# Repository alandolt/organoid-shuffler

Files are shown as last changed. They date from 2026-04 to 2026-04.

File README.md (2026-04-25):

# MicroNinjas - Organoid Sorting

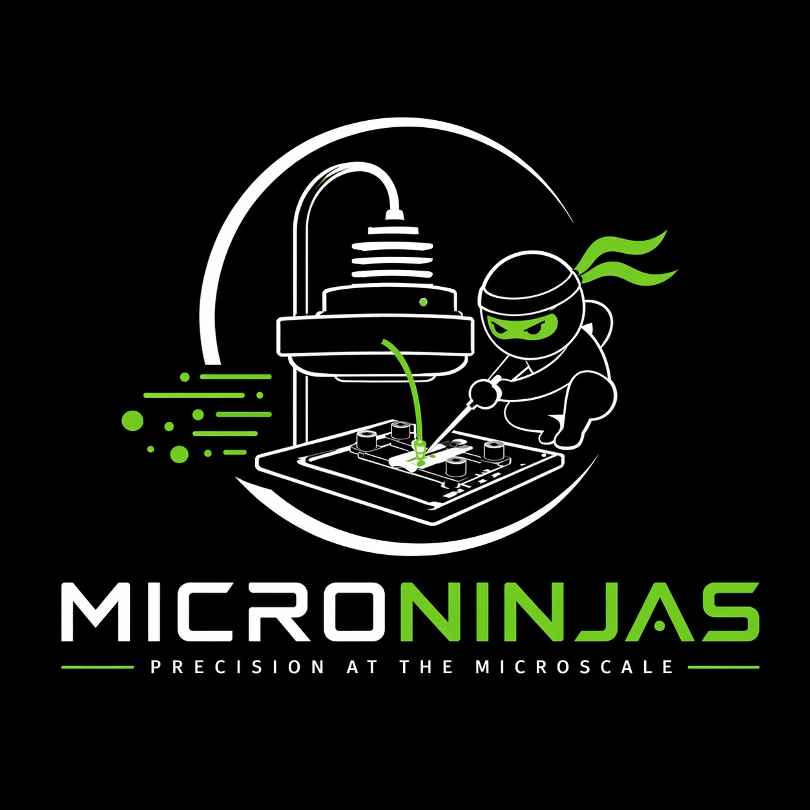
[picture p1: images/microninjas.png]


*EMBO Hackathon Hack your Microscope 2026 in Oeiras, Portugal.*

This project was developed during a hands-on hackathon focused on building open, functional microscopy and microfluidic systems from the ground up. The goal was not just to prototype ideas, but to design, build, and test complete working pipelines under real constraints.

Participants: Alex Landolt, Mai Rahmoon, Olyssa Sperling, Kartik Totlani, Enrico Piperno

Tutors: Sunil Kumar, Dumisile Lumkwana 

## The challenge
We tackled size-based sorting of organoids in microfluidic flow.

The task required:

* Detecting organoids in real time inside a microfluidic chip
* Classifying them based on size
* Actively sorting them into multiple outlets
* Closing the loop with automated control and verification

We built a closed-loop system that integrates: flow → image → classify → actuate → verify

## [Brainstorming and Fabrication of microfluidic chip](https://github.com/alandolt/organoid-shuffler/blob/master/Microfluids1x1.md)

## Experimental setup
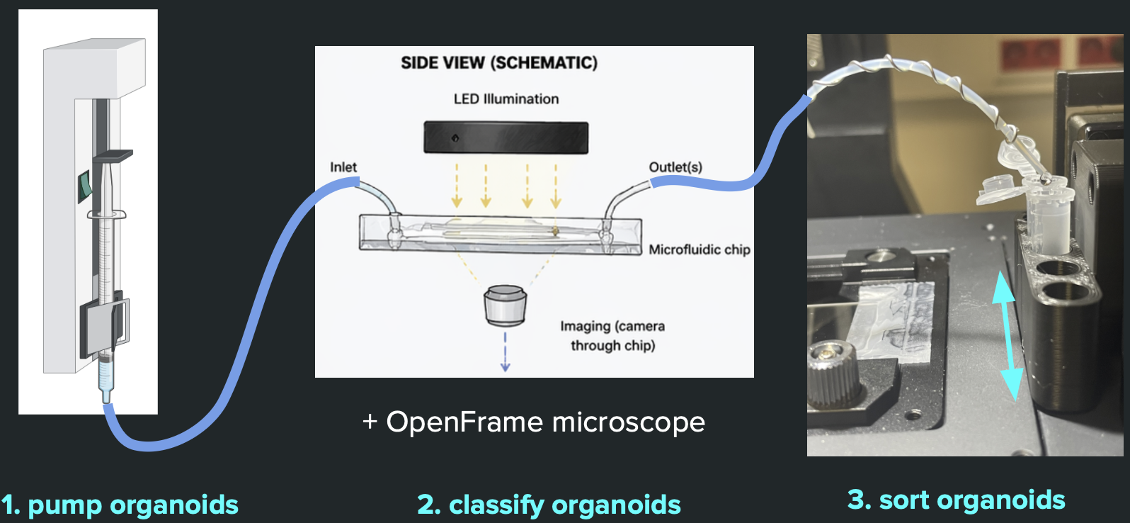
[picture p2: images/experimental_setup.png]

The final experimental setup consists of:

* one automatable syringe pump by the [Poseidon design](https://github.com/pachterlab/poseidon)
* a [microfluidic chip by IBIDI](https://ibidi.com/channel-slides/50--slide-i-luer.html) mounted on an [OpenFrame fluorescence microscope](https://cairn-research.co.uk/product/openframe-microscope/) by cairn research
* the sorting mechanism crafted by a one-axis translation stage, and a 3D printed 0.5 ml [Eppendorf tube adapter](eppendorf_0.5ml_adapter.stl).
The parts are connected using silicon and teflon tubing.

## Microfluidic actuation
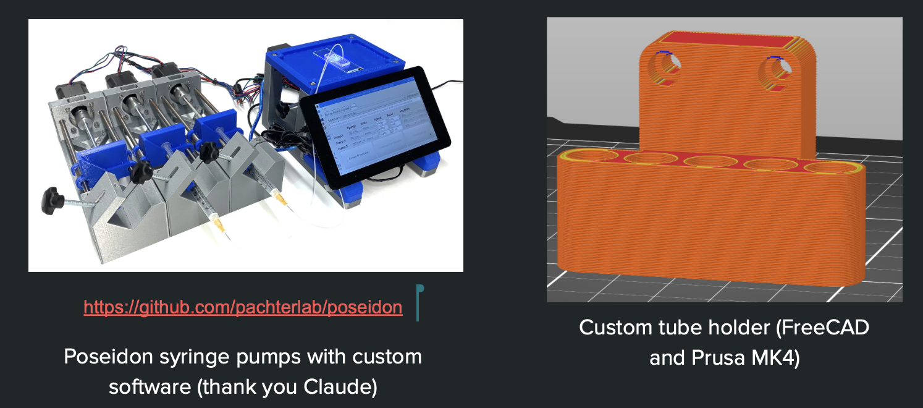
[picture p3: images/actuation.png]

We actuated our microfluidic chips with the open-source Poseidon design. 
We wrote custom scripts to actuate the stepper motors and then calibrated the pumps to convert from steps to mm (travel stage dependent) and then mm to ml (syringe dependent). 
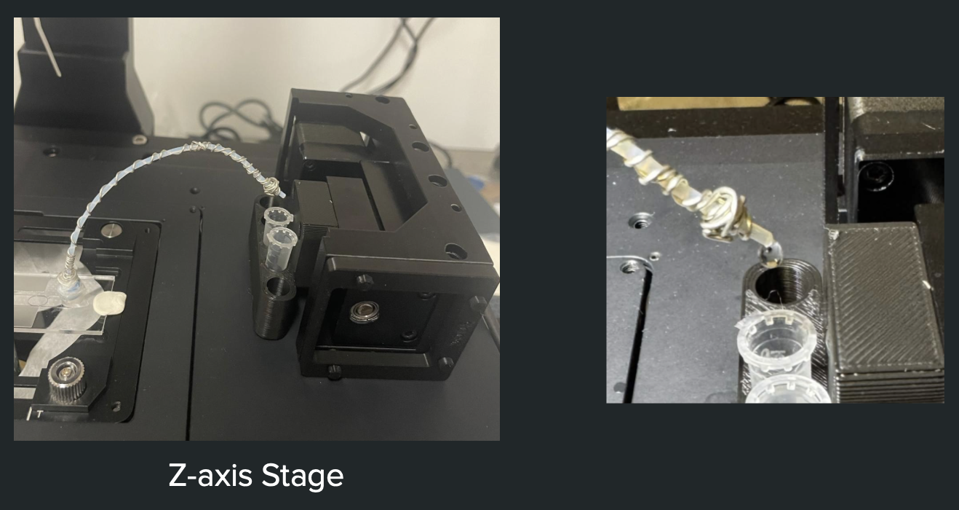
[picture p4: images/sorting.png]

This way we were able control flow precisely up to 1 ul/s. The pump control was done manually first with cnc_stepper_motor.py and cnc_stepper_motor.ino flashed on the Arduino UNO. 

## Image analysis
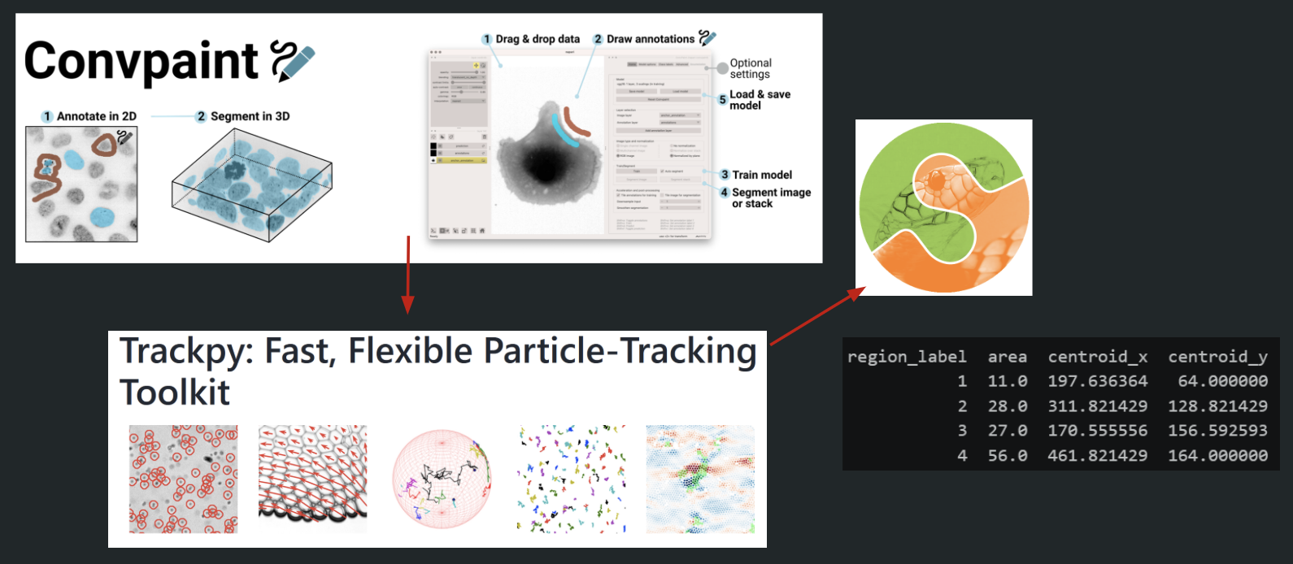
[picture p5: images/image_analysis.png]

Using the syringe pumps we achieved a controlled flow of organoids through the chip that was imaged in real-time at 1 f/s. 
In order to use the pipeline, please follow the instructions in the notebook Pipeline.ipynb, which will guide you through the different steps of the pipeline.
The pipeline does the following steps:
* Snaps an image from the microscope
* Segments the image using the trained Convpaint model
* Cleans up the segmentation mask using some morphological operations
* Measures the size of the detected organoids (the segmented objects in class 2)
* Tracks the detected organoids across frames using trackpy
* If an organoid is detected that is bigger than 100 pixels in the field of view, it moves it to eppendorf slot 1 for 30s, otherwise it moves it to slot 0.
* All detections and sorting decisions are logged in a parquet file for later analysis.
* The flow in the chip is controlled by setting a flowrate of 0.001 ml/min in the pump that controls the flow rate in the chip (the one connected to the inlet). You can directly set the flowrate through the jupyter notebook.

## Results
(https://youtu.be/Kiy7haI36f4 "Click to play on Youtube.com")

## Discussion
The organoids were smaller and rarer than expected since the sample was very dilute. 

In the end we managed to find some, train the classification model on them and start the sorting procedure.

In the future we can use the speed calculation in order to calculate the time of the organoid reaching the end of the tubing, matching the exact time for the organoid to drop into the sorting Eppendorf tubings.

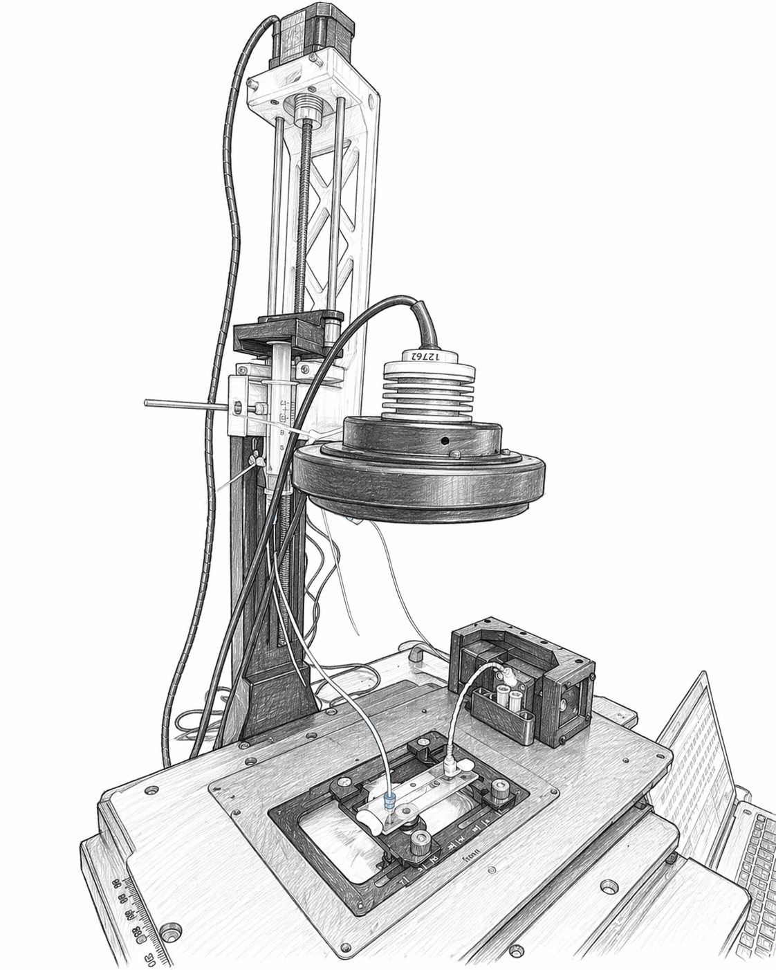
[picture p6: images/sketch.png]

Sketch generated using ChatGPT that very accurately represents our setup.

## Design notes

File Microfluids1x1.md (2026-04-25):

# Challenge -1: Organoid sorting

## Brainstorming on possible microfluidic device configuration

### 1. Passive spiral sorter without active sorting

A possible way to sort particles of different sizes passively is using a spiral microfluidic device with 2 inlets and several outlets. Over the course of flow, the particles can be separated based on inertia and centrifugal forces. Since the real time imaging and feedback-controlled sorting was a deliverable of the course, the spiral sorter chip wasn’t used.

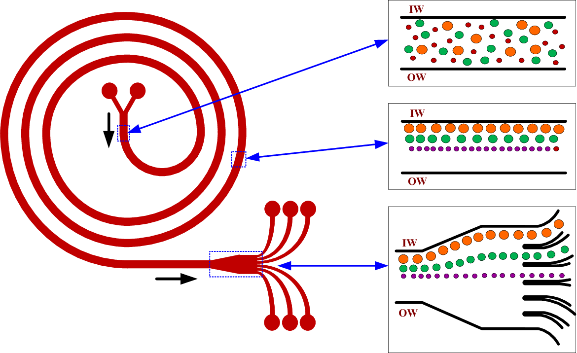
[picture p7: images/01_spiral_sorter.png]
Passive spiral sorter schematic


### 2. Microfluidic device with detection and hydrodynamic actuation

A possible solution to sort particles based on the size was using a microfluidic channel with hydrodynamic actuation using image driven flow control (as shown in the figure below). Briefly, the organoids can be injected and spaced using a sheath flow towards the imaging area, where the detection and analysis occur. Once the sorting decision is made, the flow is actuated within the channel to drive the organoids into one of the collection channels.

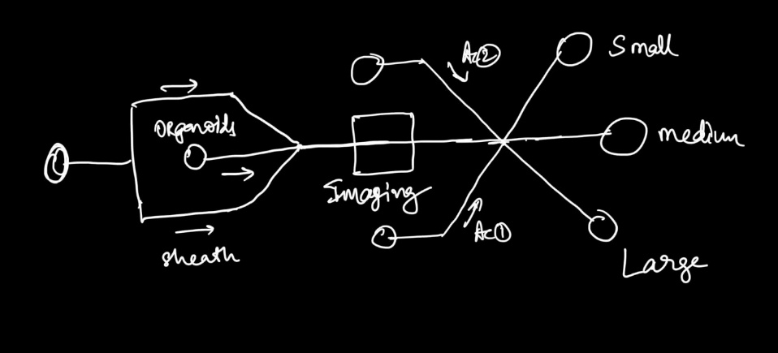
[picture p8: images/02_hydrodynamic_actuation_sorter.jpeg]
Hydrodynamic actuation-based sorting schematic


### 3. Simple microfluidic device for imaging and sorting controlled by linear collection control

The third option was to use a simple microfluidic device (single inlet and single outlet) for imaging the organoids on chip and automating the collection. The mold for the Eppendorf tubes was 3D printed and mounted on a X-Y linear motor. The imaging, analysis an

## Microfabrication

We used two methods to fabricate the microfluidic devices used for the project.

### 1. Laser cutting

PMMA sheets as well as dual sided tape were cut using a CO₂ laser (add a link to the laser cutter).

Laser-cut microfluidic devices were rapidly fabricated by structuring poly(methyl methacrylate) (PMMA) sheets and assembling them with double-sided adhesive tape as an intermediate spacer and bonding layer. In this approach, channel geometries and inlet/outlet ports were first defined in CAD and transferred to PMMA and adhesive films using a CO₂ laser cutter, with the adhesive layer typically determining the channel height (180 µm). After cutting, the layers were aligned using inlet holes and laminated together by pressing the adhesive between rigid PMMA substrates, forming enclosed microchannels without the need for cleanroom processing.

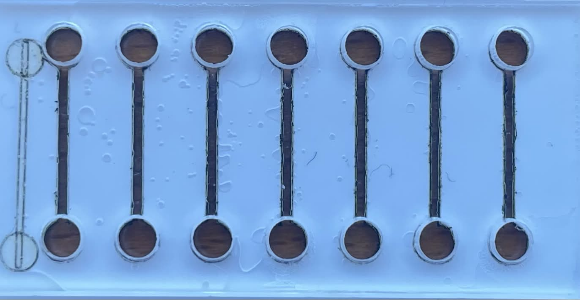
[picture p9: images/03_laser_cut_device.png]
Laser-cut microfluidic devices


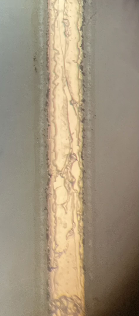
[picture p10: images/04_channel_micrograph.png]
Laser-cut channel micrograph


### 2. Soft lithography

Soft lithography is the standard method for fabricating microfluidic devices due to its high resolution and reliability. PDMS stamps were prepared by pouring a mixture of PDMS elastomer and curing agent (typically in a 10:1 weight ratio) over a microstructured silicon wafer mold. The mixture is degassed to remove air bubbles and then cured at elevated temperatures (typically 65-150 °C). After curing, the PDMS layer was peeled from the mold, diced into individual devices, and inlet / outlet ports are created using biopsy punches. The PDMS devices were subsequently cleaned and irreversibly bonded to glass substrates using oxygen plasma treatment, forming enclosed microfluidic channels.

[Soft lithography reference DOI](https://doi.org/10.1002/(SICI)1521-3773(19980316)37:5%3C550::AID-ANIE550%3E3.0.CO;2-G)

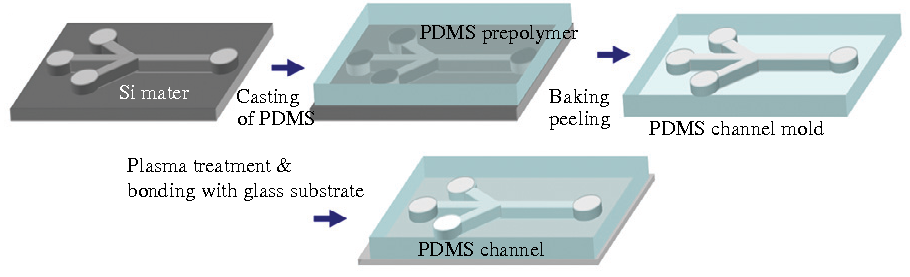
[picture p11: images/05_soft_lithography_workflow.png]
Soft lithography workflow


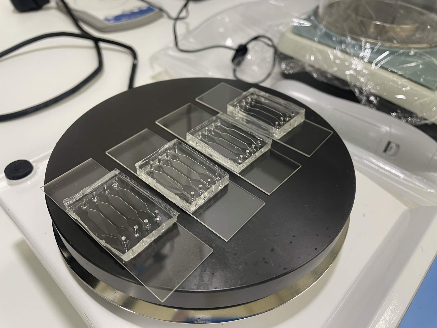
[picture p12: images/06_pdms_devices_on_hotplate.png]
PDMS devices on a hotplate


Microfluidic device schematic

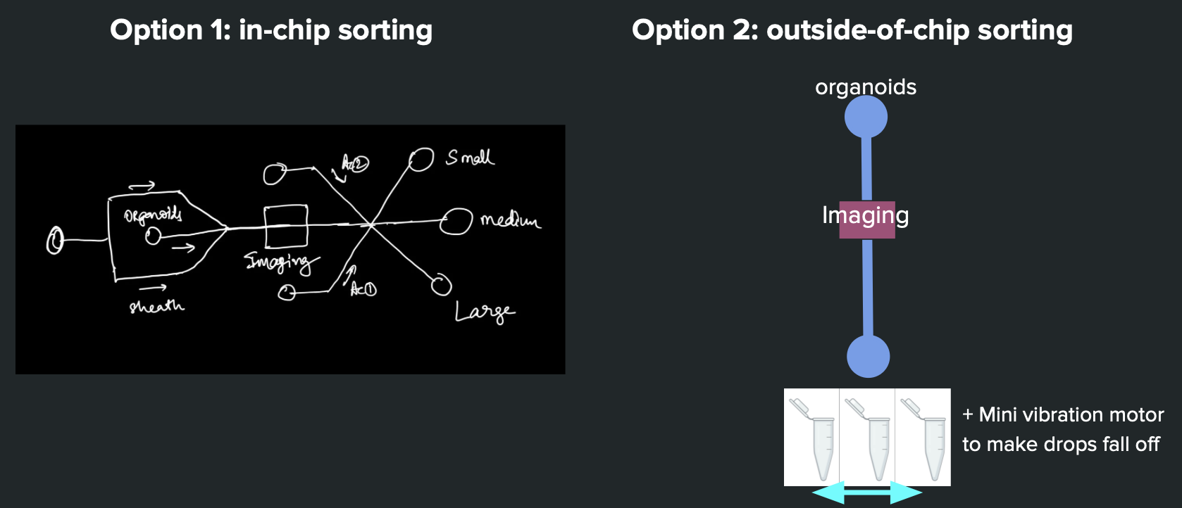
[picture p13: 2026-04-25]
images/chip_design.png

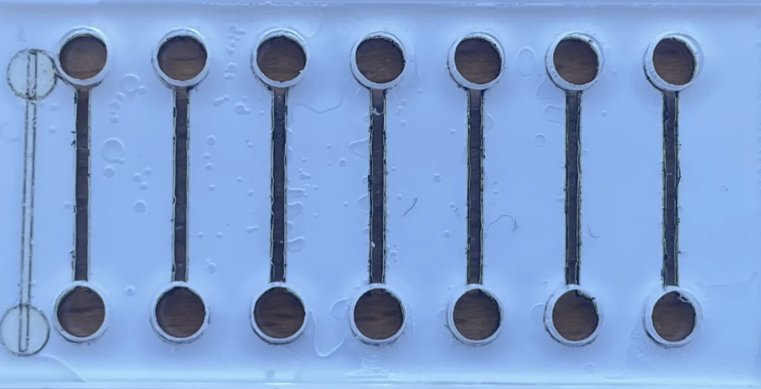
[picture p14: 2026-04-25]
images/lasercutting1.png

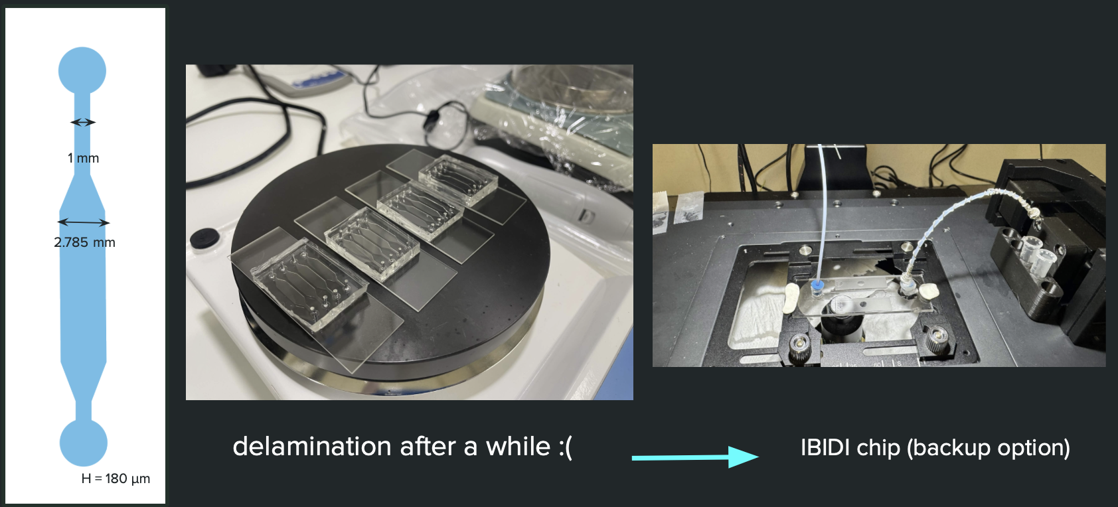
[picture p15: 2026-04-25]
images/soft_lithography.png

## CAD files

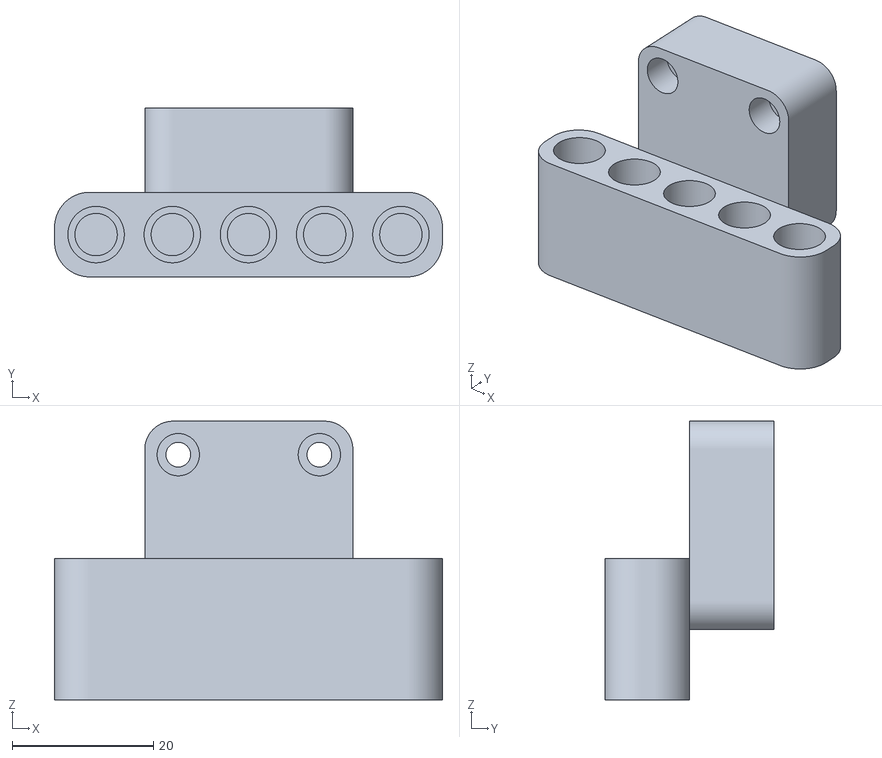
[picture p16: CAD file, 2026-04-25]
eppendorf_0.5ml_adapter.stl
55.0 x 23.9 x 39.5

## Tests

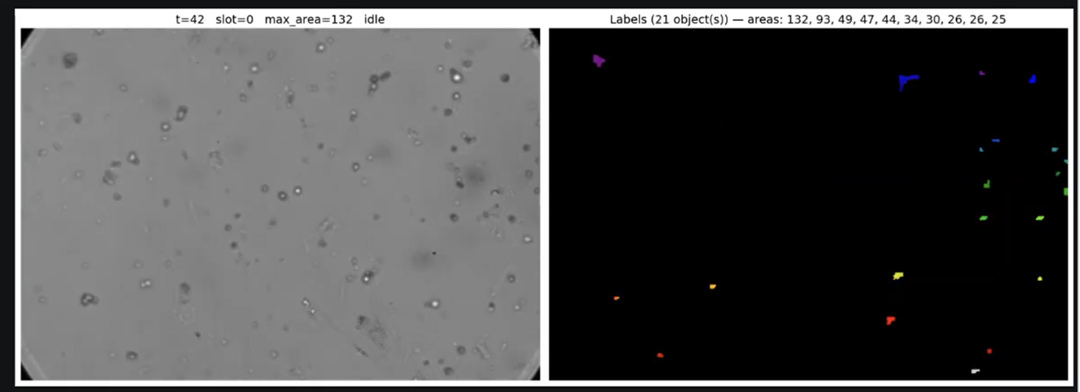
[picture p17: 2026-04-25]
images/results.png

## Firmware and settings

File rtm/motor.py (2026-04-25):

"""Motor and pump actuation.

Two tiers:

- **Stubs** (:func:`move_eppendorf`, :func:`actuate_pump`): no hardware — just
  print. These are the defaults wired into the run cells.
- **Real drivers** over an Arduino CNC shield. One Arduino speaks to up to
  three stepper axes (X/Y/Z) over a single serial port, one command per line::

      {axis}{steps},{speed_steps}\\n        e.g. "X1000000000,4000\\n"

  Share the port via :class:`CncShield`, then bind axis-level drivers to it:

      shield = CncShield(port="COM3").connect()
      pump  = StepperFlowPump(shield,  axis="X")  # continuous flow
      stage = StepperPositioner(shield, axis="Y")  # discrete moves

  Each axis is independent — `pump.set_flow(0.5)` and `stage.move_mm(25)` can
  happen concurrently; the shield serializes writes with a lock.
"""
from __future__ import annotations

import threading
import time

# Lazy: keep the module importable even without pyserial. Classes raise
# ImportError only when someone actually tries to construct them.
try:
    import serial  # type: ignore  # pyserial
except ImportError:
    serial = None  # type: ignore


# ----------------------------------------------------------------------
# Stubs
# ----------------------------------------------------------------------

def move_eppendorf(position: int) -> None:
    """Move the eppendorf collection stage to *position* (integer slot index).

    Called once per sorted organoid. Placeholder — swap for the real driver
    call (e.g. bind to :meth:`StepperPositioner.move_to_slot`).
    """
    print(f"[motor] move_eppendorf(position={position})")


def actuate_pump(speed: int) -> None:
    """Set the flow-chamber pump speed (integer setpoint).

    Called every frame with a new flow-speed estimate. Placeholder — swap for
    the real driver call (e.g. bind to :meth:`StepperFlowPump.set_flow`).
    """
    print(f"[pump]  actuate_pump(speed={speed})")


def position_from_size(size: float, thresholds: list[tuple[float, int]]) -> int:
    """Pick a position from *size* using a list of ``(upper_bound, position)`` rules.

    First rule whose ``size <= upper_bound`` wins. The final rule should use
    ``float('inf')`` as the catch-all upper bound.

    Example:
        >>> position_from_size(1200, [(500, 1), (2000, 2), (float('inf'), 3)])
        2
    """
    for upper, pos in thresholds:
        if size <= upper:
            return pos
    raise ValueError(
        "No matching rule in thresholds — add a (float('inf'), ...) catch-all."
    )


# ----------------------------------------------------------------------
# Serial link: one per Arduino, shared across axes
# ----------------------------------------------------------------------

_VALID_AXES = ("X", "Y", "Z")


class CncShield:
    """Serial link to one Arduino CNC shield. Shared by all axis drivers.

    Call :meth:`connect` once, then attach :class:`StepperFlowPump`,
    :class:`StepperPositioner`, or other axis drivers by passing ``self``.
    :meth:`send` is thread-safe.
    """

    BOOT_DELAY_S = 2.0   # Arduino resets on serial open; give it time
    DISABLE_FORMAT = "{axis}OFF\n"  # firmware-side verb for cutting coil current

    def __init__(self, port: str, baud: int = 115200):
        if serial is None:
            raise ImportError(
                "pyserial is required for CncShield — `pip install pyserial`"
            )
        self.port = port
        self.baud = baud
        self._ser = None
        self._lock = threading.Lock()

    def connect(self) -> "CncShield":
        """Open the serial port. Blocks ~2 s while the Arduino resets."""
        self._ser = serial.Serial(self.port, self.baud, timeout=1)
        time.sleep(self.BOOT_DELAY_S)
        return self

    def close(self) -> None:
        if self._ser is not None:
            self._ser.close()
            self._ser = None

    def __enter__(self) -> "CncShield":
        return self.connect()

    def __exit__(self, *exc) -> None:
        self.close()

    def send(self, axis: str, steps: int, speed_steps: int) -> None:
        """Write one motion command to the shield. Thread-safe.

        Raises:
            RuntimeError: if the shield is not connected.
            ValueError: if *axis* is not X/Y/Z.
        """
        if axis not in _VALID_AXES:
            raise ValueError(f"axis must be X/Y/Z; got {axis!r}")
        if self._ser is None:
            raise RuntimeError("CncShield is not connected; call .connect() first")
        cmd = f"{axis}{int(steps)},{int(speed_steps)}\n".encode()
        with self._lock:
            self._ser.write(cmd)

    def disable(self, axis: str) -> None:
        """Cut coil current on *axis* (release holding torque). Thread-safe.

        Sends ``DISABLE_FORMAT.format(axis=axis)`` — firmware must recognize
        this verb. Override :attr:`DISABLE_FORMAT` if your firmware differs.
        """
        if axis not in _VALID_AXES:
            raise ValueError(f"axis must be X/Y/Z; got {axis!r}")
        if self._ser is None:
            raise RuntimeError("CncShield is not connected; call .connect() first")
        cmd = self.DISABLE_FORMAT.format(axis=axis).encode()
        with self._lock:
            self._ser.write(cmd)


# ----------------------------------------------------------------------
# Continuous-flow pump (one axis)
# ----------------------------------------------------------------------
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

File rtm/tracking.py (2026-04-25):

"""Online particle tracking with trackpy over a sliding window.

Re-links all observations within a rolling window of the last ``window_frames``
frames. Assigns stable global particle IDs across re-links so tracks can be
identified across calls, and emits "completed" tracks once a particle has not
been observed for more than ``memory`` frames.

Hackable surface:

- ``search_range`` / ``memory`` — forwarded to :func:`trackpy.link`.
- ``window_frames`` — how far back to keep observations; also sets the horizon
  after which a missing particle is considered to have left the FOV.
- ``flow_speed(..., aggregator=np.median)`` — swap the aggregator for ``max``,
  ``mean``, or a custom callable.
"""
from __future__ import annotations

from collections import Counter
from typing import Callable

import numpy as np
import pandas as pd
import trackpy as tp

# Silence trackpy's per-call "Frame X: N trajectories present" prints.
tp.quiet()


_OBS_COLS = [
    "obs_id",
    "frame",
    "x",
    "y",
    "area",
    "bbox_min_row",
    "bbox_min_col",
    "bbox_max_row",
    "bbox_max_col",
]


def _empty_obs_df() -> pd.DataFrame:
    return pd.DataFrame({c: pd.Series(dtype="float64") for c in _OBS_COLS})


class ParticleTracker:
    def __init__(
        self,
        *,
        search_range: float = 15.0,
        memory: int = 1,
        window_frames: int = 50,
    ):
        self.search_range = search_range
        self.memory = memory
        self.window_frames = window_frames

        self._obs: pd.DataFrame = _empty_obs_df()
        self._obs_to_particle: dict[int, int] = {}
        self._emitted: set[int] = set()
        self._next_obs_id: int = 0
        self._next_particle_id: int = 0

    # ------------------------------------------------------------------
    # Ingest
    # ------------------------------------------------------------------

    def update(self, regions: pd.DataFrame, timestep: int) -> pd.DataFrame:
        """Ingest this frame's regions and return linked observations in the window.

        *regions* is the DataFrame produced by :func:`rtm.segmentation.measure_regions`.
        Returns a DataFrame with columns ``obs_id, frame, x, y, area, ...,
        particle`` (the ``particle`` column holds stable global IDs).
        """
        if not regions.empty:
            new = regions.rename(
                columns={"centroid_x": "x", "centroid_y": "y"}
            )[[
                "x", "y", "area",
                "bbox_min_row", "bbox_min_col", "bbox_max_row", "bbox_max_col",
            ]].copy()
            new["frame"] = timestep
            n = len(new)
            new["obs_id"] = np.arange(self._next_obs_id, self._next_obs_id + n)
            self._next_obs_id += n
            self._obs = pd.concat([self._obs, new[_OBS_COLS]], ignore_index=True)

        # Drop observations that fell out of the window.
        horizon = timestep - self.window_frames
        self._obs = self._obs[self._obs["frame"] > horizon].reset_index(drop=True)
        keep_ids = set(self._obs["obs_id"].astype(int).tolist())
        self._obs_to_particle = {
            oid: pid for oid, pid in self._obs_to_particle.items() if oid in keep_ids
        }

        if self._obs.empty:
            return self._obs.assign(particle=pd.Series(dtype="int64"))

        linked = tp.link(
            self._obs.copy(),
            search_range=self.search_range,
            memory=self.memory,
        )
        linked["particle"] = self._assign_stable_ids(linked)
        return linked

    # ------------------------------------------------------------------
    # Queries
    # ------------------------------------------------------------------

    def pop_completed_tracks(
        self, tracks: pd.DataFrame, timestep: int
    ) -> pd.DataFrame:
        """Return (and mark emitted) tracks whose last obs is older than ``memory``.

        A track is "completed" when no observation has been seen for more than
        ``memory`` frames. Once returned, it will not be returned again.
        """
        if tracks.empty:
            return tracks

        last_frame = tracks.groupby("particle")["frame"].max()
        done_mask = (last_frame < timestep - self.memory) & (
            ~last_frame.index.isin(self._emitted)
        )
        done_ids = last_frame[done_mask].index.tolist()
        if not done_ids:
            return tracks.iloc[0:0].copy()

        self._emitted.update(done_ids)
        return tracks[tracks["particle"].isin(done_ids)].copy()

    def flow_speed(
        self,
        tracks: pd.DataFrame,
        *,
        aggregator: Callable[[list[float]], float] = np.median,
    ) -> float | None:
        """Aggregate per-particle instantaneous speed (px/frame) across active tracks.

        Speed for a particle uses its last two observations. Returns ``None``
        when no particle has at least two observations.
        """
        if tracks.empty:
            return None

        speeds: list[float] = []
        for _, grp in tracks.groupby("particle", sort=False):
            if len(grp) < 2:
                continue
            g = grp.sort_values("frame")
            dx = g["x"].iloc[-1] - g["x"].iloc[-2]
            dy = g["y"].iloc[-1] - g["y"].iloc[-2]
            dt = g["frame"].iloc[-1] - g["frame"].iloc[-2]
            if dt > 0:
                speeds.append(float(np.hypot(dx, dy) / dt))
        if not speeds:
            return None
        return float(aggregator(speeds))

    # ------------------------------------------------------------------
    # Internals
    # ------------------------------------------------------------------

    def _assign_stable_ids(self, linked: pd.DataFrame) -> np.ndarray:
        """Map trackpy's per-call ``particle`` IDs to stable global IDs.

        For each trackpy group, the most common existing global ID among its
        observations wins; if the group has no known observations, a fresh
        global ID is minted.
        """
        stable = np.empty(len(linked), dtype=np.int64)
        for _, grp in linked.groupby("particle", sort=False):
            existing = [
                self._obs_to_particle[int(oid)]
                for oid in grp["obs_id"]
                if int(oid) in self._obs_to_particle
            ]
            if existing:
                pid = Counter(existing).most_common(1)[0][0]
            else:
                pid = self._next_particle_id
                self._next_particle_id += 1
            for oid in grp["obs_id"]:
                self._obs_to_particle[int(oid)] = pid
            stable[grp.index.to_numpy()] = pid
        return stable
